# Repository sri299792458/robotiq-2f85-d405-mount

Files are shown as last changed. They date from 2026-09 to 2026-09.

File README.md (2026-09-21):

# Robotiq 2F-85 D405 mount

One-piece PETG wrist camera mount for the RealSense D405 on the Robotiq 2F-85. The R2 design preserves the existing two-screw gripper seat and adds a fixed camera plate, two support ribs, protective rails, and cable-tie slots. It aims the camera toward the TPU fingers for contact views.

<p align="center">
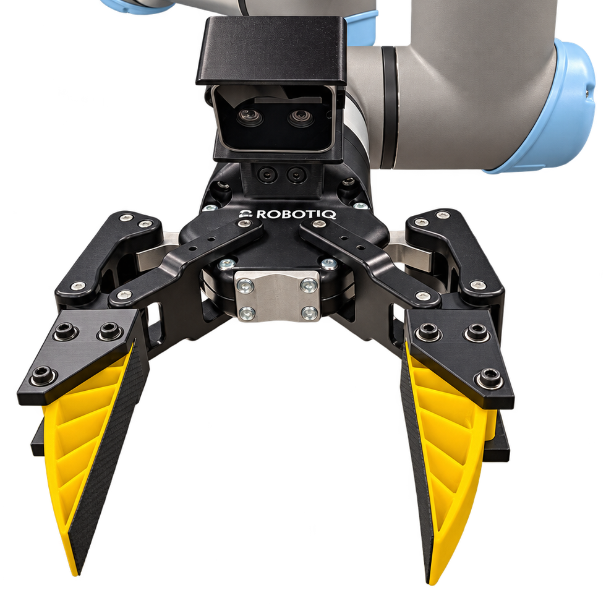
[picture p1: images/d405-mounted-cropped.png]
RealSense D405 mounted above the Robotiq 2F-85 and yellow TPU fingers
  
</p>

Installed prototype with the D405 above the TPU fingers.

## Print and assemble

Download the **[R2 print package](D405_wrist_mount_R2_print_package.zip)** or the **[print-ready STL](D405_wrist_mount_R2_PRINT.stl)**. Print one copy in PETG, in millimeters at 100% scale, using the supplied orientation.

Read the **[print and assembly guide](PRINT_AND_ASSEMBLY.md)** for print settings, support placement, screw lengths, cable routing, camera framing, and verification limits. The guide is also included in the print package.

## CAD and source

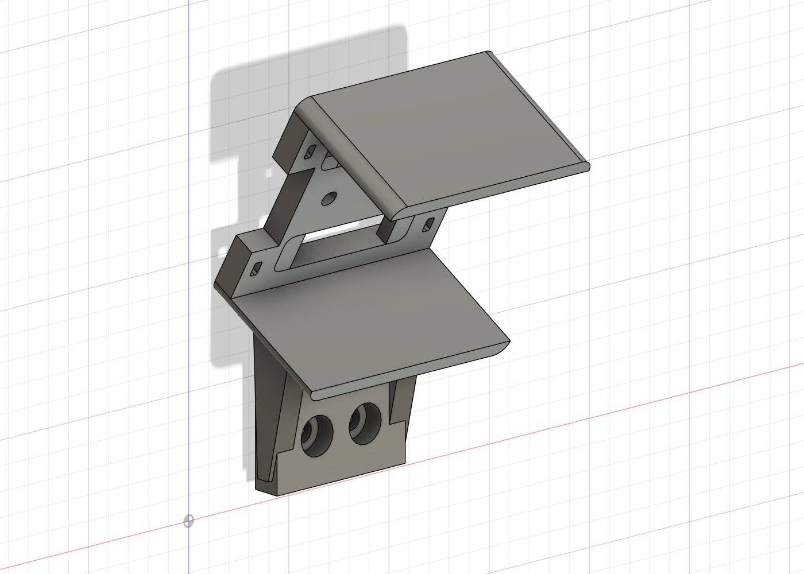
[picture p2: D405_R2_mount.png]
D405 protected wrist mount R2 CAD view


| File | Purpose |
| --- | --- |
| [STEP model](D405_wrist_mount_R2.step) | Editable mount in the gripper assembly frame |
| [Fusion archive](D405_R2_mount.f3d) | Editable Fusion CAD |
| [Build script](build_mount.py) | CadQuery generator and mechanical checks |
| [Preserved mounting seat](reference/preserved_two_screw_seat.step) | Included source geometry for the two-screw interface |
| [Requirements](requirements.txt) | Python dependency versions used for this release |
| [SHA-256 manifest](SHA256.json) | Checksums of the supplied R2 release files |

The mount source and its required mounting-seat geometry are included here. To rebuild, use Python 3.10 in a copy of this directory:

```sh
python -m pip install -r requirements.txt
python build_mount.py
```

The generator overwrites the mount STEP, print STL, and mechanical check results, and produces a camera envelope and preview mesh. Rebuild a copy to preserve the supplied release files and checksums. It does not regenerate the Fusion archive, rendered images, or optical and Fusion check results; see the [rebuild notes](PRINT_AND_ASSEMBLY.md#rebuilding-the-mount).

## Assembly and verification

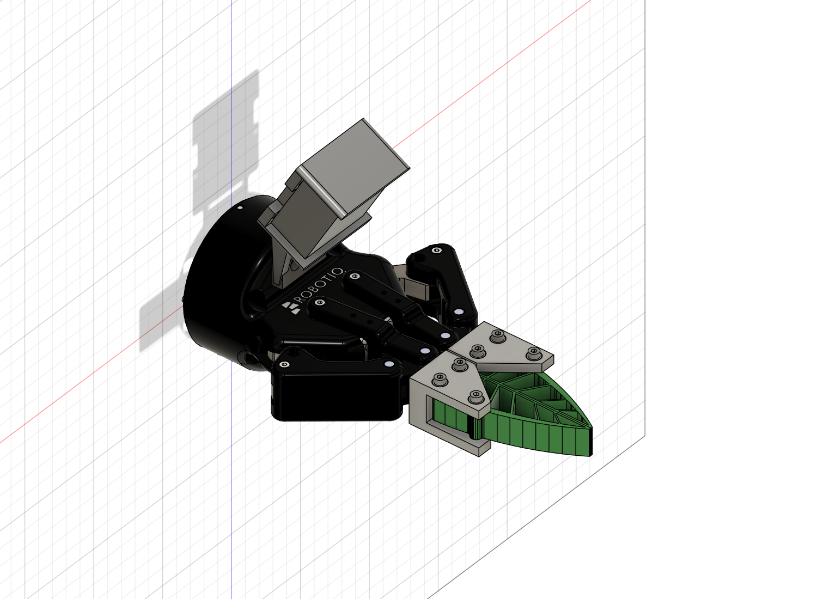
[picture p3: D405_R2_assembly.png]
Mount placement on the Robotiq assembly


The camera is shown as a dimensioned envelope. The recorded [mechanical checks](mechanical_checks.json) and [closed-assembly Fusion check](fusion_closed_check.json) pass for the nominal geometry. The [optical checks](optical_checks.json) and [synthetic lens views](D405_R2_optical_views.png) document the camera framing assumptions.

This is a printable prototype. Physical fit, full gripper motion, camera depth quality, cable behavior, mount stiffness, and impact resistance still need verification. The opening envelope is a geometric check, not solved gripper kinematics or simulated TPU deformation. Follow the assembly guide and perform a slow, unloaded opening/closing check before use.

## Companion gripper

The PETG finger adapters, TPU fingers, print packs, and gripper build scripts are maintained in [robotiq-2f85-umi-gripper](https://github.com/sri299792458/robotiq-2f85-umi-gripper). This mount's recorded closed-assembly check used the V2.2 adapters and TPU finger reference from that project.

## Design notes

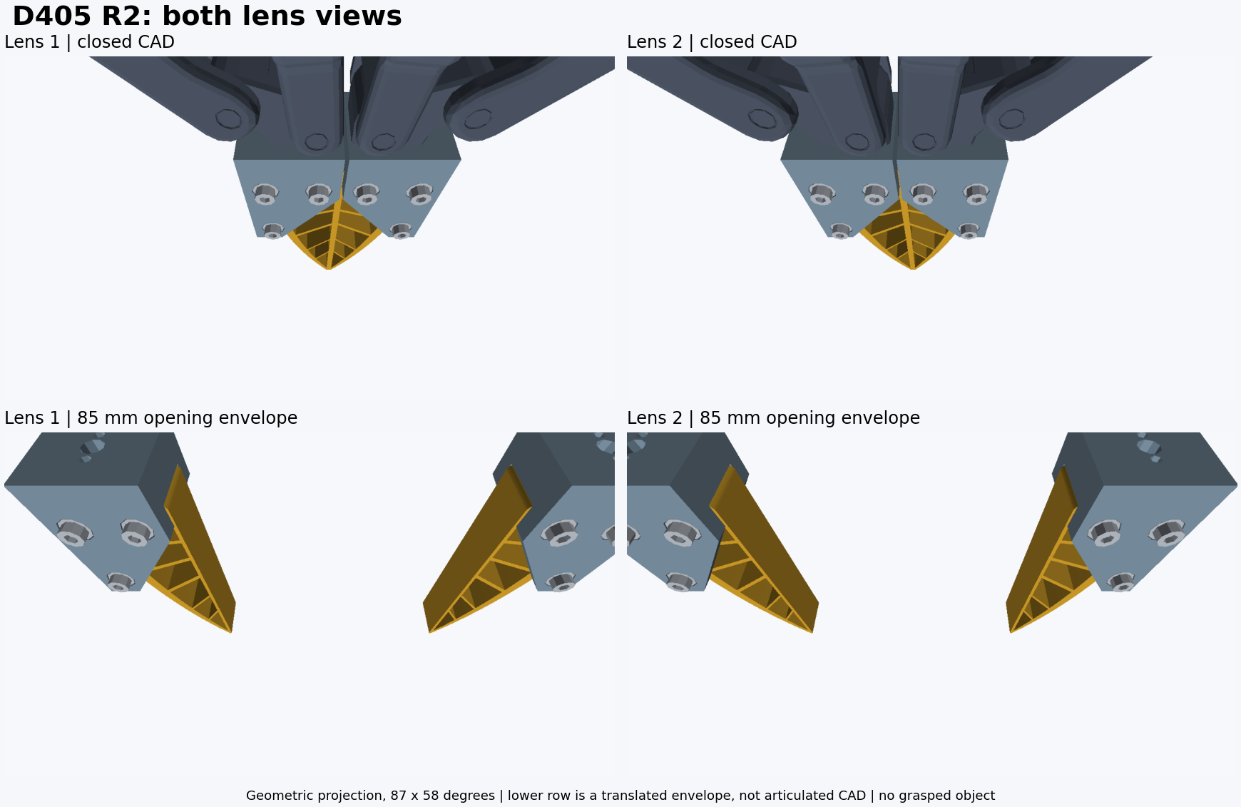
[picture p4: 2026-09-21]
D405_R2_optical_views.png

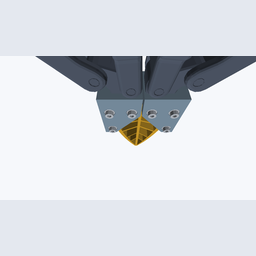
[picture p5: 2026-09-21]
policy_256_lens_1_closed.png

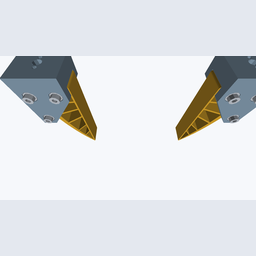
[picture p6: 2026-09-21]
policy_256_lens_1_opening_envelope.png

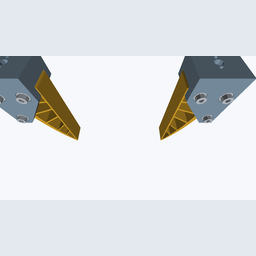
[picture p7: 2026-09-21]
policy_256_lens_2_opening_envelope.png

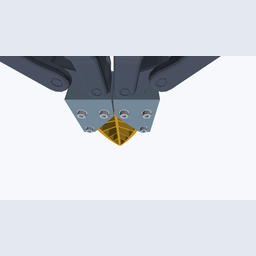
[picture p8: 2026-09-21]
policy_256_lens_2_closed.png

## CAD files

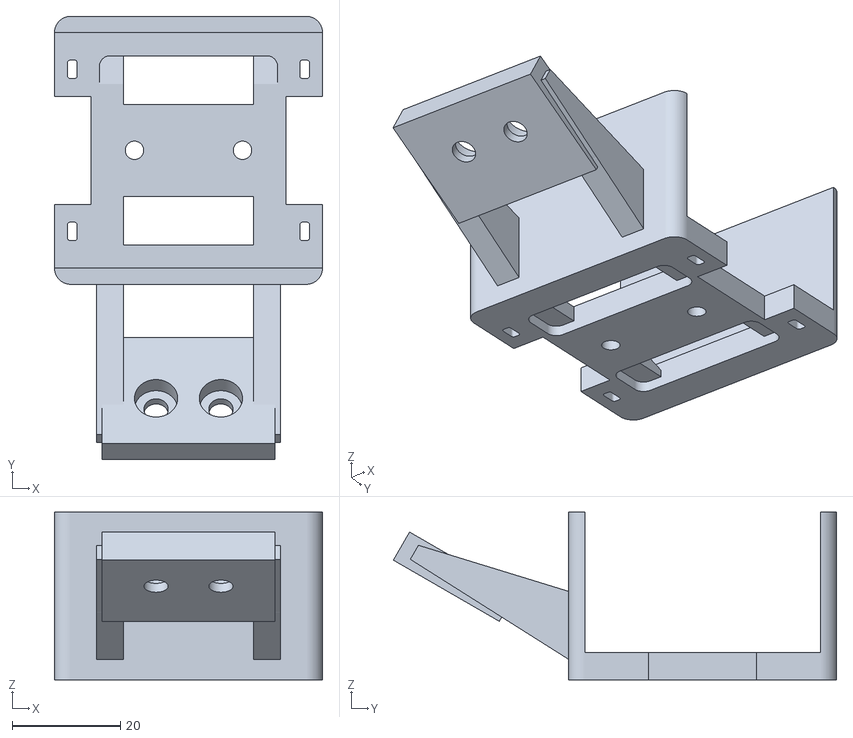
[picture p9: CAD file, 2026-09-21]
D405_wrist_mount_R2_PRINT.stl
49.6 x 82.1 x 31.0

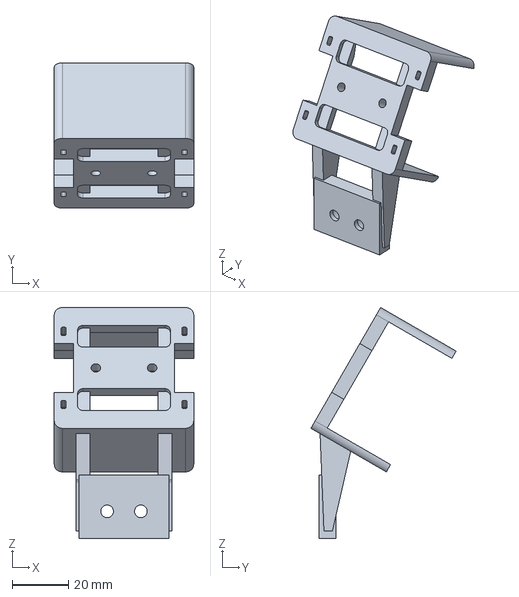
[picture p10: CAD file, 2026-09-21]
D405_wrist_mount_R2.step
49.6 x 51.6 x 82.1 mm

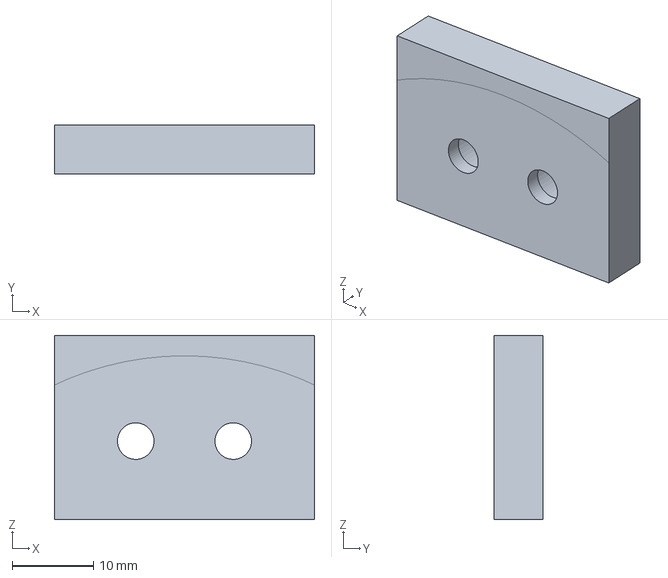
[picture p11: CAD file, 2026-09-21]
reference/preserved_two_screw_seat.step
32.0 x 6.00 x 22.6 mm

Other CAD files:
D405_R2_mount.f3d

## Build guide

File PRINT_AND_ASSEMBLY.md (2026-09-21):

# D405 protected wrist mount R2

Print **D405_wrist_mount_R2_PRINT.stl**, one copy, millimetres, 100% scale.
It is already oriented with the flat camera rear plate on the bed and the
camera opening pointing upward. Size: **49.6 × 82.05 × 31.0 mm**.

Suggested starting settings for a 0.4 mm nozzle:

- PETG, 0.20 mm layers, 6 walls, 6 top/bottom layers, 40% gyroid infill.
- Supports enabled **everywhere** for the mounting arm and overhanging
  gripper seat. The two continuous guard rails have no window bridges. Use your PETG profile's removable support
  interface; do not limit supports to the build plate.
- A 5 mm brim is useful for adhesion. Keep the supplied orientation.
- Clear all supports, the two camera bores, the original recessed mounting
  holes and the cable-tie slots before assembly. Smooth the cable contact edges.

## Hardware and assembly

1. Reuse the existing **two gripper mounting screws**. Their 12 mm centre
   spacing, 4.5 mm clearance bores, 8 mm recesses and seating geometry are
   retained from the confirmed printed mount. The component is on the
   **screw-head side of the gripper**, facing the latest TPU fingers.
2. Slide the D405 through the open front, with its two lenses horizontally
   across the jaws. The 43.6 mm cavity gives 0.8 mm nominal clearance per side.
   Both side centres are open so the USB housing can pass during insertion.
3. Secure the camera from the rear with **two M3×8 socket-head screws and
   0.5 mm plain washers**. The 5 mm plate leaves about **2.5 mm** in the camera.
   RealSense specifies a maximum M3 insertion of **4 mm**. M3×10 is too long
   for this stack. Tighten gently by hand; no powered driver or printed torque
   value is specified.
4. Plug in the USB cable. Use 2.5 mm cable ties through the paired side-rail
   slots to secure the cable jacket behind the camera, leaving a relaxed bend
   at the plug. The clearance check used a straight 20 × 10 mm plug envelope
   projecting 40 mm from either side. Check a different/right-angle plug on
   the hardware.
5. Check seating, camera retention and cable clearance, then perform a slow,
   unloaded gripper opening/closing check before collecting demonstrations.

## What changed

R2 simplifies the windowed R1 cage into two continuous protective rails with
rounded exterior corners, projecting 3 mm beyond the nominal camera front.
The two large guard windows and four small front corner returns are removed.
The 5 mm camera plate, two 5 mm support ribs, rear ventilation openings and
functional cable-tie slots remain. Both sides remain open for USB access.

The outer dimensions and optical pose are unchanged from R1. This adds about
2.6 g of PETG at solid density, eliminates the guard's window bridges and avoids
the open-ended corner tabs. The guard is intended for incidental broad contact,
not as a sealed enclosure or validated crash protection.

Only the mating seat from the old print is carried over. The frame is 49.6 mm
wide; its maximum outward coordinate is 99.48 mm in the vendor gripper frame,
approximately the old print's outward envelope. Camera front centre is
(0, 70, 64) mm in that frame, with the view directed forward and inward.

## Mechanical assessment

The main arrangement is straightforward: camera screws into a rigid plate,
two ribs connect that plate to the gripper seat, and two solid rails protect
the camera edges. There are no adjustment joints, snap fits or extra guard
fasteners. The assembly has one printed part and four screws in total.

The solid rails remove a flexible span present in the old windowed guard.
This is a structural improvement in layout, not a measured strength rating.
The original screw seat still has 1.9 mm of plastic beneath each recessed
screw head, and several internal transitions remain abrupt. Avoid excessive
screw tightening. Check for rocking at the seat and camera movement under
modest handling and robot motion before relying on it for data collection.
Neither stiffness, impact survival nor long-term creep has been physically
tested. R2 is the current print prototype.

## Camera mode and policy images

The design targets **848×480 depth capture**, with the full wrist image resized
for a **224 or 256 pixel policy input**. The physical view should be retained:
aspect-ratio-preserving resize and padding is one option. A centre square crop
can remove an open jaw, so review any policy's crop/augmentation pipeline.
Resizing a captured image does not change the depth sensor's near limit.

RealSense's published minimum depth is **70 mm at 848×480** and **100 mm at
1280×720**. The recommended working range extends to 500 mm; that is not a
hard far clipping plane. These stereo depth limits do not define RGB visibility.

Both lens origins were checked with an 18 mm baseline and the published depth
origin 3.7 mm behind the front glass. Results for this R2:

| Geometric check | Result |
| --- | --- |
| Entire TPU geometry, closed CAD | 88–160 mm axial depth |
| Exposed TPU, closed CAD | 115–160 mm axial depth |
| Exposed TPU opening/bending envelope | **97–165 mm** axial depth |
| Envelope inside both lens views | Pass, even using a narrower 82° × 56° view |
| Carrier intruding into either expanded 94° × 68° lens cone | Zero solid overlap |

The envelope samples each jaw outward by 0/20/42.5 mm, retracted by 0/15 mm,
and independently displaced ±10 mm in X and Z. This is a geometric stress
envelope, **not solved Robotiq kinematics or simulated TPU deformation**.
The final design deliberately does not require every sampled point to stay
beyond the 720p depth limit.

At 224 pixels across the full image, a 43.5 mm exposed-rail reference segment
projects to roughly 17 pixels. Small deformations can therefore be below one
pixel. The wrist image supplies contact context; this geometry check does not
establish force sensing or policy performance. No marker visibility constraint
was used.

## Checks and remaining physical verification

- Exported STL is watertight, consistently wound and one connected component.
- BRep is valid; the original mounting seat is retained with zero missing volume.
- No overlap with the nominal camera, USB housing/insertion sweep, straight
  plug envelopes or the checked screwdriver access cylinders.
- Fusion reports zero collisions against the 33 visible bodies of the closed
  Robotiq assembly and latest V2.2 adapter / TPU finger reference.
- Actual camera intrinsics, stereo fill rate, motion blur, arbitrary grasp
  occlusion, full articulated stroke, cable bending, stiffness and impact
  resistance have not been physically tested. This is a printable prototype.

The older printed design had angle/framing work and a farther camera position.
The near-range concern raised during this revision arose from the new closer
draft; it did not demonstrate a depth-range fault in the old printed mount.

## Files

- `D405_wrist_mount_R2_PRINT.stl`: print this one part.
- `D405_wrist_mount_R2.step`: editable solid in the gripper assembly frame.
- `D405_R2_mount.f3d`: local Fusion archive of the mount.
- `D405_R2_mount.png`: clear standalone view of the printable part.
- `D405_R2_assembly.png`: placement with the latest fingers. Camera shown as a
  dimensioned envelope, not detailed vendor CAD.
- `D405_R2_optical_views.png`: synthetic lens projections; lower row is the
  translated opening envelope, not an articulated assembly.
- `policy_256_*.png`: the same geometric projections at 256-square input size.
- `mechanical_checks.json`, `optical_checks.json`, `fusion_closed_check.json`:
  numeric check results.
- `build_mount.py` and `reference/preserved_two_screw_seat.step`: reproduce the
  solid and mechanical checks with CadQuery, NumPy, trimesh and Shapely.
- `requirements.txt`: versions used to rebuild this release with Python 3.10.

## Rebuilding the mount

In a Python 3.10 environment, run from this directory:

```sh
python -m pip install -r requirements.txt
python build_mount.py
```

The generator reads the included mounting-seat STEP and writes the mount STEP,
print STL, camera envelope, preview mesh and mechanical check results beside
the script. Rebuild a copy of the directory to preserve the release files and
their checksums. `SHA256.json` identifies the supplied release files; STEP
export timestamps can change when rebuilding.

The optical and Fusion JSON files record checks from the design session.
Rebuilding the solid does not rerun those checks or regenerate the Fusion
archive and rendered images.

## Source dimensions

[RealSense D400 datasheet, July 2023](https://www.realsenseai.com/wp-content/uploads/2023/07/Intel-RealSense-D400-Series-Datasheet-July-2023.pdf),
Tables 4-11, 4-16, 4-20 and Figure 10-13 (pages 89, 94, 97, 150).
[D405 product specifications](https://www.realsenseai.com/products/stereo-depth-camera-d405/)
give the nominal 87° × 58° field of view and recommended 7–50 cm range.
